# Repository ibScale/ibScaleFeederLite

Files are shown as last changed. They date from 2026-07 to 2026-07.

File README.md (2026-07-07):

# ibScaleFeederLite

`ibScaleFeederLite` is an updated version of the [Opulo LumenPNP Rev 12 Feeder](https://github.com/opulo-inc/feeder) motherboard with several enhancements.

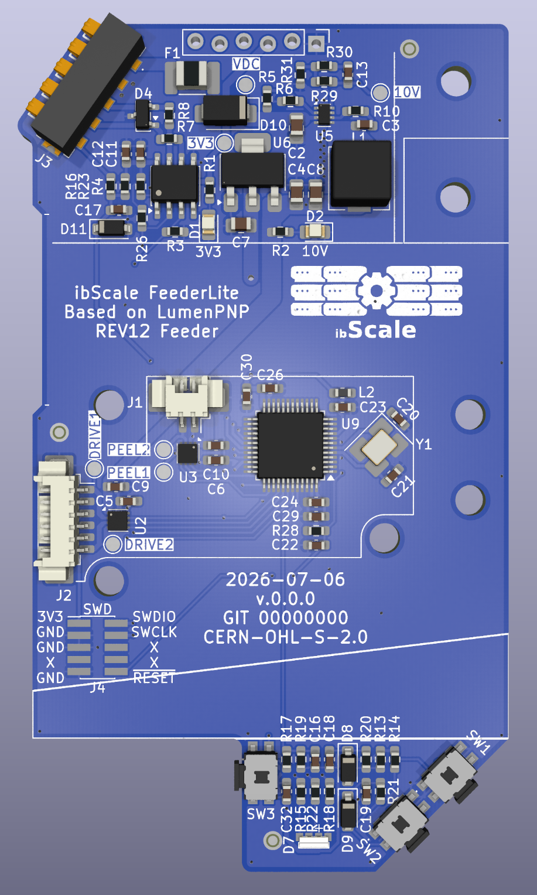
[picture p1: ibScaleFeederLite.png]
ibScaleFeederLite


## What's different from the Rev 12 motherboard

### PCB Stackup
The PCB is a 4-layer stackup with 7628 prepreg. The cost difference is negligible compared to the original 2-layer stackup. This allows for a cleaner layout with improved routing and component placement. The bottom layer of the PCB is kept as a ground layer only with no traces. Since this layer of the PCB is exposed it is very likely to get knicked, scratched, or otherwise damaged by the environment. This prevents any minor damage from affecting the operation of the feeder.

### DC/DC buck converter
The original OnSemi MC34063AD design used a 100µF input and 470µF output electrolytic capacitors. These capacitors are relatively expensive and difficult to source in low-profile heights suitable for the 8mm feeders. The large 100uF input capacitance would also cause arcing during insertion from the inrush current while charging. In addition to this, if the LumenPNP had 50 feeders plugged in the excessive bus capacitance would cause power sag (brown out) or potentially even trip the over-current protection. If the over-current protection does trip then the LumenPNP will boot loop as the 24V DC supply resets.

A Texas Instruments TPS563300 with MLCC capacitors has replaced the original design. The input capacitance has been reduced to 10uF to help prevent arcing during insertion. The reduced capacitance also helps mitigate the excessive bus capacitance start-up issue. A 0.75A PPTC fuse (F1) and diode (D1) have also been added to provide over-current and reverse-current protection.

### RS-485 transceiver
The AD/Maxim MAX3078E transceiver is the single most expensive component on the Opulo Rev12 feeder. Since the LumenPNP only operates at 57600bps there is no need to have an expensive part. The new TI THVD1400D transceiver is about 1/10th the cost and more then adequate for this application.

### Status LED
The RGB status LED has been changed to a Lite-On LTST-S33FBEGW-5A. This LED has a translucent diffuser and is designed for low current applications. It is available from a variety of suppliers and is an overall better quality indicator.

### Buttons
The original buttons were probably one of the biggest pain points on the original Rev12 design. These have been upgraded to Diptronics PTCF-V-T/R with J-hook stems. These switches are larger and available from a variety of suppliers. This along with improved debounce circuitry provide a better user experience.

### SWD connector
The original placement of the SWD connector made it difficult to use commonly available POGO pin clips like the Adafruit 5434. The connector was rotated and moved to the edge of the PCB to make using POGO pin clips easier.

## Hardware overview

| Function | Part |
|---|---|
| MCU | STM32F031C6T6 (Arm Cortex-M0, 48 MHz, 32 KB flash) |
| Motor drivers (Drive / Peel) | 2x TI DRV8837 |
| RS-485 transceiver | TI THVD1400D |
| Buck regulator | TI TPS563300 |
| Status LED | Lite-On LTST-S33FBEGW-5A |
| UP/DOWN/BOOT switches | Diptronics PTCF-V-T/R |

## Repository structure

```
ibScaleFeederLite/
├── ibScaleFeederLite.kicad_pro   KiCad project file
├── ibScaleFeederLite.kicad_pcb   PCB layout
├── ibScaleFeederLite.kicad_sch   Schematic
├── library/                      Project-specific symbols, footprints, and 3D models
└── references/                   Component datasheets
```

## Opening the project

Requires [KiCad](https://www.kicad.org/) 10 or newer. Open `ibScaleFeederLite.kicad_pro` to get started.

All custom symbols, footprints, and 3D models used by the project are included in `library/` and referenced via the project-local `sym-lib-table` and `fp-lib-table`, so no additional library setup is required.

## Bill of materials

Every component includes the manufacturer's name and part number, along with DigiKey, Mouser, and LCSC part numbers. To export a BOM, use KiCad's schematic editor: **Tools → Generate Bill of Materials**.

## License

Released under the [CERN Open Hardware Licence Version 2 - Strongly Reciprocal (CERN-OHL-S-2.0)](LICENSE.txt), consistent with the licensing of the original Opulo LumenPNP hardware it is derived from.

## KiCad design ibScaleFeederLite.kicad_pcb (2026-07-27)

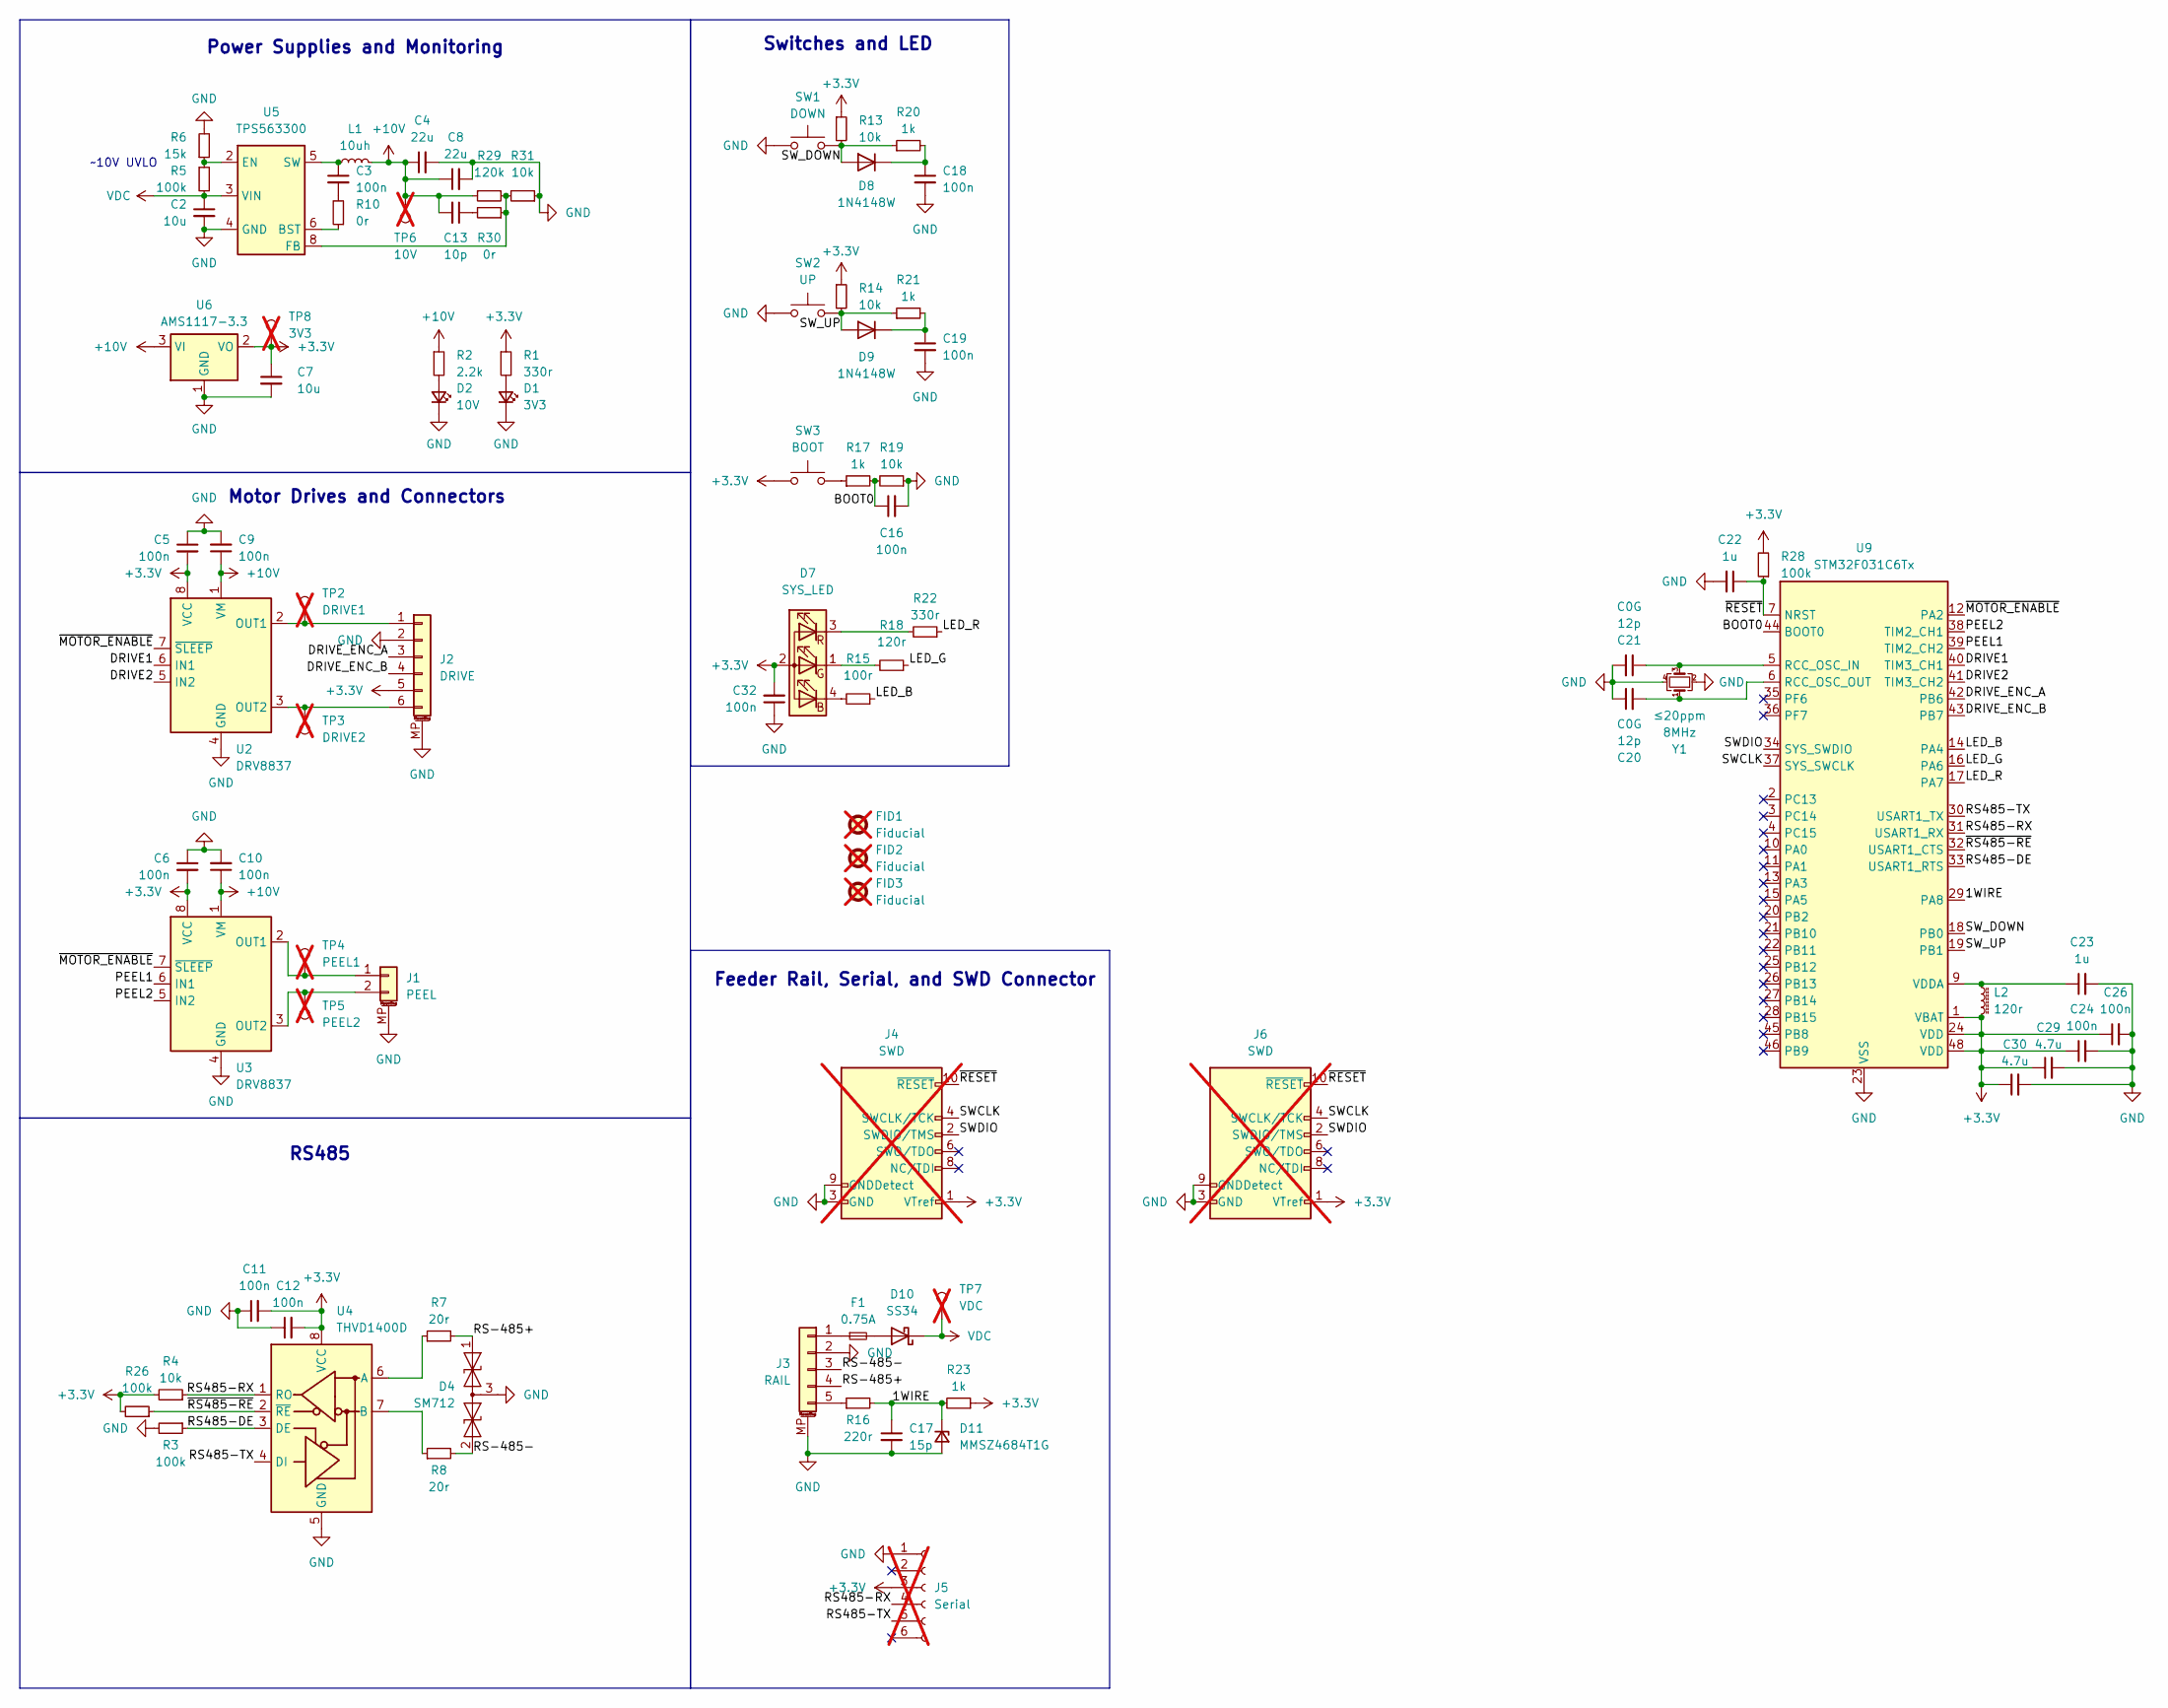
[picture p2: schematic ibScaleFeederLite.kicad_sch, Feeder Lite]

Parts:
C2: 10u; C_0805_2012Metric_Pad1.18x1.45mm_HandSolder; Tolerance X5R; Rating 50V; Manufacturer_Part GRM21BR61H106KE43L; Mouser 81-GRM21BR61H106KE3L
C3: 100n; C_0603_1608Metric_Pad1.08x0.95mm_HandSolder; Tolerance X5R; Rating 50V; Manufacturer_Part CC0603KRX7R9BB104; Mouser 603-CC603KRX7R9BB104
C4, C8: 22u; C_0805_2012Metric_Pad1.18x1.45mm_HandSolder; Tolerance X5R; Rating 25V; Manufacturer_Part CL21A226MAQNNNE; Mouser 187-CL21A226MAQNNNE
C5, C6, C9, C10, C11, C12, C24, C26: 100n; C_0603_1608Metric_Pad1.08x0.95mm_HandSolder; Manufacturer_Part CC0603KRX7R9BB104; LCSC C14663
C7: 10u; C_0805_2012Metric_Pad1.18x1.45mm_HandSolder; Manufacturer_Part GRM21BR61H106KE43L; LCSC C440198
C13: 10p; C_0603_1608Metric_Pad1.08x0.95mm_HandSolder; Tolerance CG0; Rating 25V; Manufacturer_Part CL10C100JB8NNNC; Mouser 187-CL10C100JB8NNNC
C16, C18, C19, C32: 100n; C_0603_1608Metric_Pad1.08x0.95mm_HandSolder; Manufacturer_Part CC0603KRX7R9BB104; DigiKey 311-1344-1-ND
C17: 15p; C_0603_1608Metric_Pad1.08x0.95mm_HandSolder; Manufacturer_Part CL10C150JB8NNNC; Mouser 187-CL10C150JB8NNNC
C20, C21: 12p; C_0603_1608Metric_Pad1.08x0.95mm_HandSolder; Rating C0G; Tolerance 1%; Manufacturer_Part CL10C120JB8NNNC; LCSC C38523
C22, C23: 1u; C_0603_1608Metric_Pad1.08x0.95mm_HandSolder; Manufacturer_Part CL10A105KB8NNNC; LCSC C15849
C29, C30: 4.7u; C_0603_1608Metric_Pad1.08x0.95mm_HandSolder; Manufacturer_Part CL10A475KO8NNNC; LCSC C19666
D1: 3V3; LED_0805_2012Metric_Pad1.15x1.40mm_HandSolder; Rating If=20ma, Vf=2.2v; Tolerance green; Manufacturer_Part LG R971-KN-1-0-20-R18; LCSC C2297
D2: 10V; LED_0805_2012Metric_Pad1.15x1.40mm_HandSolder; Rating If=20ma, Vf=2.2v; Tolerance green; Manufacturer_Part LG R971-KN-1-0-20-R18; LCSC C2297
D4: SM712; SOT-23; Manufacturer_Part SM712-02HTG; Mouser 576-SM712-02HTG
D7: SYS_LED; LED-SMD_4P-L3.0-W1.0-SIDE_LTST-S33FBEGW-5A; Manufacturer_Part LTST-S33FBEGW-5A; Mouser 859-LTST-S33FBEGW-5A
D8, D9: 1N4148W; D_SOD-123; Manufacturer_Part 1N4148WGW; LCSC C81598
D10: SS34; D_SMA; Manufacturer_Part SS34ALH; Mouser 821-SS34ALH
D11: MMSZ4684T1G; D_SOD-123; Manufacturer_Part MMSZ4684T1G; Mouser 863-MMSZ4684T1G
F1: 0.75A; Fuse_1812_4532Metric_Pad1.30x3.40mm_HandSolder; Manufacturer_Part PTS181233V075; Mouser 504-PTS181233V075
FID1, FID2, FID3: Fiducial; Fiducial_1mm_Mask2mm; not fitted
J1: PEEL; Molex_PicoBlade_53261-0271_1x02-1MP_P1.25mm_Horizontal; Manufacturer_Part 53261-0271; Mouser 538-53261-0271
J2: DRIVE; Molex_PicoBlade_53261-0671_1x06-1MP_P1.25mm_Horizontal; Manufacturer_Part 53048-0610; Mouser 538-53048-0610
J3: RAIL; 009155005541006; Manufacturer_Part 009155005541006; Mouser 581-009155005541006
J4, J6: SWD; PinHeader_2x05_P1.27mm_Vertical_SMD; not fitted
J5: Serial; PinHeader_1.27mm_1x06_FrictionFit; not fitted
L1: 10uh; L_TDK_VLS6045EX_VLS6045AF; Manufacturer_Part VLS6045EX-100M; Mouser 810-VLS6045EX-100M
L2: 120r; L_0603_1608Metric_Pad1.05x0.95mm_HandSolder; Manufacturer_Part MFBM1V1608-121-R; LCSC C14709
R1: 330r; R_0603_1608Metric_Pad0.98x0.95mm_HandSolder; Manufacturer_Part RC0603FR-13330RL; Mouser 603-RC0603FR-13330RL
R2: 2.2k; R_0603_1608Metric_Pad0.98x0.95mm_HandSolder; Manufacturer_Part RT0603FRE132K2L; LCSC C4190
R3, R26: 100k; R_0603_1608Metric_Pad0.98x0.95mm_HandSolder; Manufacturer_Part RC0603JR-13100KL; LCSC C25803
R4, R13, R14, R19: 10k; R_0603_1608Metric_Pad0.98x0.95mm_HandSolder; Manufacturer_Part RC0603FR-0710KP; LCSC C25804
R5, R28: 100k; R_0603_1608Metric_Pad0.98x0.95mm_HandSolder; Manufacturer_Part RC0603JR-13100KL; Mouser 603-RC0603JR-13100KL
R6: 15k; R_0603_1608Metric_Pad0.98x0.95mm_HandSolder; Manufacturer_Part WR06X153 JTL; Mouser 791-WR06X153JTL
R7, R8: 20r; R_0603_1608Metric_Pad0.98x0.95mm_HandSolder; Manufacturer_Part AC0603JR-0720RL; Mouser 603-AC0603JR-0720RL
R10, R30: 0r; R_0603_1608Metric_Pad0.98x0.95mm_HandSolder; Tolerance 1%; Manufacturer_Part RC0603FR-100RL; Mouser 603-RC0603FR-100RL
R15: 100r; R_0603_1608Metric_Pad0.98x0.95mm_HandSolder; Manufacturer_Part RK73H1JTTD1000F; LCSC C22775
R16: 220r; R_0603_1608Metric_Pad0.98x0.95mm_HandSolder; Manufacturer_Part RMCF0603JT220R; Mouser 708-RMCF0603JT220R
R17, R20, R21, R23: 1k; R_0603_1608Metric_Pad0.98x0.95mm_HandSolder; Manufacturer_Part RC0603FR-131KL; LCSC C21190
R18: 120r; R_0603_1608Metric_Pad0.98x0.95mm_HandSolder; Manufacturer_Part RMCF0603FT120R; LCSC C22787
R22: 330r; R_0603_1608Metric_Pad0.98x0.95mm_HandSolder; Manufacturer_Part RC0603FR-13330RL; LCSC C23138
R29: 120k; R_0603_1608Metric_Pad0.98x0.95mm_HandSolder; Tolerance 1%; Manufacturer_Part RC0603JR-07120KL; Mouser 603-RC0603JR-07120KL
R31: 10k; R_0603_1608Metric_Pad0.98x0.95mm_HandSolder; Tolerance 1%; Manufacturer_Part RC0603FR-0710KP; Mouser 603-RC0603FR-0710KP
SW1: DOWN; PTCFVTR; Manufacturer_Part PTCF-V-T/R; Mouser 113-PTCF-V-T/R
SW2: UP; PTCFVTR; Manufacturer_Part PTCF-V-T/R; Mouser 113-PTCF-V-T/R
SW3: BOOT; PTCFVTR; Manufacturer_Part PTCF-V-T/R; Mouser 113-PTCF-V-T/R
TP2: DRIVE1; TestPoint_Pad_D1.5mm; not fitted
TP3: DRIVE2; TestPoint_Pad_D1.5mm; not fitted
TP4: PEEL1; TestPoint_Pad_D1.5mm; not fitted
TP5: PEEL2; TestPoint_Pad_D1.5mm; not fitted
TP6: 10V; TestPoint_Pad_D1.5mm; not fitted
TP7: VDC; TestPoint_Pad_D1.5mm; not fitted
TP8: 3V3; TestPoint_Pad_D1.5mm; not fitted
U2, U3: DRV8837; WSON-8-1EP_2x2mm_P0.5mm_EP0.9x1.6mm_ThermalVias; Manufacturer_Part DRV8837DSGR; Mouser 595-DRV8837DSGR
U4: THVD1400D; SOIC-8_3.9x4.9mm_P1.27mm; Manufacturer_Part THVD1400DR; Mouser 595-THVD1400DR
U5: TPS563300; SOT-583-8; Manufacturer_Part TPS563300DRLR; Mouser 595-TPS563300DRLR
U6: AMS1117-3.3; SOT-223-3_TabPin2; Manufacturer_Part LM1117MPX-3.3/NOPB; Mouser 926-LM1117MPX3.3NOPB
U9: STM32F031C6Tx; LQFP-48_7x7mm_P0.5mm; Manufacturer_Part STM32F031C6T6TR; Mouser 511-STM32F031C6T6TR
Y1: 8MHz; Crystal_SMD_3225-4Pin_3.2x2.5mm_HandSoldering; Tolerance ≤20ppm; Manufacturer_Part ECS-80-8-33-JGN-TR3; LCSC C648984

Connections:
+3.3V: C5.2, C6.2, C7.1, C11.2, C12.2, C24.1, C26.1, C29.1, C30.1, C32.2, D7.2 (A), J2.5, J4.1 (VTref), J5.3, J6.1 (VTref), L2.2, R1.1, R4.2, R13.1, R14.1, R23.1, R26.2, R28.2, SW3.1, TP8.1 (1_1), U2.8 (VCC), U3.8 (VCC), U4.8 (VCC), U6.2 (VO), U9.1 (VBAT), U9.24 (VDD), U9.48 (VDD)
+10V: C4.1, C8.1, C9.1, C10.1, C13.2, L1.2, R2.1, R29.1, TP6.1 (1_1), U2.1 (VM), U3.1 (VM), U6.3 (VI)
/1WIRE: C17.1, D11.1 (K), R16.2, R23.2, U9.29 (PA8)
/BOOT0: C16.1, R17.2, R19.2, U9.44 (BOOT0)
/DRIVE1: U2.6 (IN1), U9.40 (TIM3_CH1)
/DRIVE2: U2.5 (IN2), U9.41 (TIM3_CH2)
/DRIVE_ENC_A: J2.3, U9.42 (PB6)
/DRIVE_ENC_B: J2.4, U9.43 (PB7)
/LED_B: R15.1, U9.14 (PA4)
/LED_G: R18.1, U9.16 (PA6)
/LED_R: R22.1, U9.17 (PA7)
/PEEL1: U3.6 (IN1), U9.39 (TIM2_CH2)
/PEEL2: U3.5 (IN2), U9.38 (TIM2_CH1)
/RS485-DE: R3.1, U4.3 (DE), U9.33 (USART1_RTS)
/RS485-RX: J5.4, R4.1, U4.1 (RO), U9.31 (USART1_RX)
/RS485-TX: J5.5, U4.4 (DI), U9.30 (USART1_TX)
/RS-485+: D4.1 (A1), J3.4, R7.2
/RS-485-: D4.2 (A2), J3.3, R8.2
/SWCLK: J4.4 (SWCLK/TCK), J6.4 (SWCLK/TCK), U9.37 (SYS_SWCLK)
/SWDIO: J4.2 (SWDIO/TMS), J6.2 (SWDIO/TMS), U9.34 (SYS_SWDIO)
/SW_DOWN: D8.2 (A), R13.2, R20.1, SW1.2, U9.18 (PB0)
/SW_UP: D9.2 (A), R14.2, R21.1, SW2.2, U9.19 (PB1)
/~MOTOR_ENABLE: U2.7 (~SLEEP), U3.7 (~SLEEP), U9.12 (PA2)
/~RESET: C22.1, J4.10 (~RESET), J6.10 (~RESET), R28.1, U9.7 (NRST)
/~RS485-RE: R26.1, U4.2 (~RE), U9.32 (USART1_CTS)
GND: C2.2, C4.2, C5.1, C6.1, C7.2, C8.2, C9.2, C10.2, C11.1, C12.1, C16.2, C17.2, C18.2, C19.2, C20.1, C21.2, C22.2, C23.2, C24.2, C26.2, C29.2, C30.2, C32.1, D1.1 (K), D2.1 (K), D4.3 (common), D11.2 (A), J1.MP (MountPin), J2.2, J2.MP (MountPin), J3.2, J3.MP (MountPin), J4.3 (GND), J4.5 (GND), J4.9 (GNDDetect), J5.1, J6.3 (GND), J6.5 (GND), J6.9 (GNDDetect), R3.2, R6.2, R19.1, R31.1, SW1.1, SW2.1, U2.4 (GND), U2.9 (GND), U3.4 (GND), U3.9 (GND), U4.5 (GND), U5.4 (GND), U6.1 (GND), U9.8 (VSSA), U9.23 (VSS), U9.47 (VSS), Y1.2, Y1.4
unnamed: C3.2, R10.2
unnamed: C13.1, R30.2
unnamed: D1.2 (A), R1.2
unnamed: D2.2 (A), R2.2
unnamed: D7.4 (BK), R15.2
unnamed: D7.1 (GK), R18.2
unnamed: D7.3 (RK), R22.2
unnamed: C18.1, D8.1 (K), R20.2
unnamed: C19.1, D9.1 (K), R21.2
unnamed: D10.2 (A), F1.2
unnamed: J1.1, TP4.1 (1_1), U3.2 (OUT1)
unnamed: J1.2, TP5.1 (1_1), U3.3 (OUT2)
unnamed: J2.1, TP2.1 (1_1), U2.2 (OUT1)
unnamed: J2.6, TP3.1 (1_1), U2.3 (OUT2)
unnamed: F1.1, J3.1
unnamed: J3.5, R16.1
unnamed: R17.1, SW3.2
unnamed: R7.1, U4.6 (A)
unnamed: R8.1, U4.7 (B)
unnamed: R10.1, U5.6 (BST)
unnamed: R5.1, R6.1, U5.2 (EN)
unnamed: R29.2, R30.1, R31.2, U5.8 (FB)
unnamed: C3.1, L1.1, U5.5 (SW)
unnamed: C21.1, U9.5 (RCC_OSC_IN), Y1.3
unnamed: C20.2, U9.6 (RCC_OSC_OUT), Y1.1
unnamed: C23.1, L2.1, U9.9 (VDDA)
VDC: C2.1, D10.1 (K), R5.2, TP7.1 (1_1), U5.3 (VIN)

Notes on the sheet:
~10V UVLO
RS485
Power Supplies and Monitoring
Feeder Rail, Serial, and SWD Connector
Motor Drives and Connectors
Switches and LED

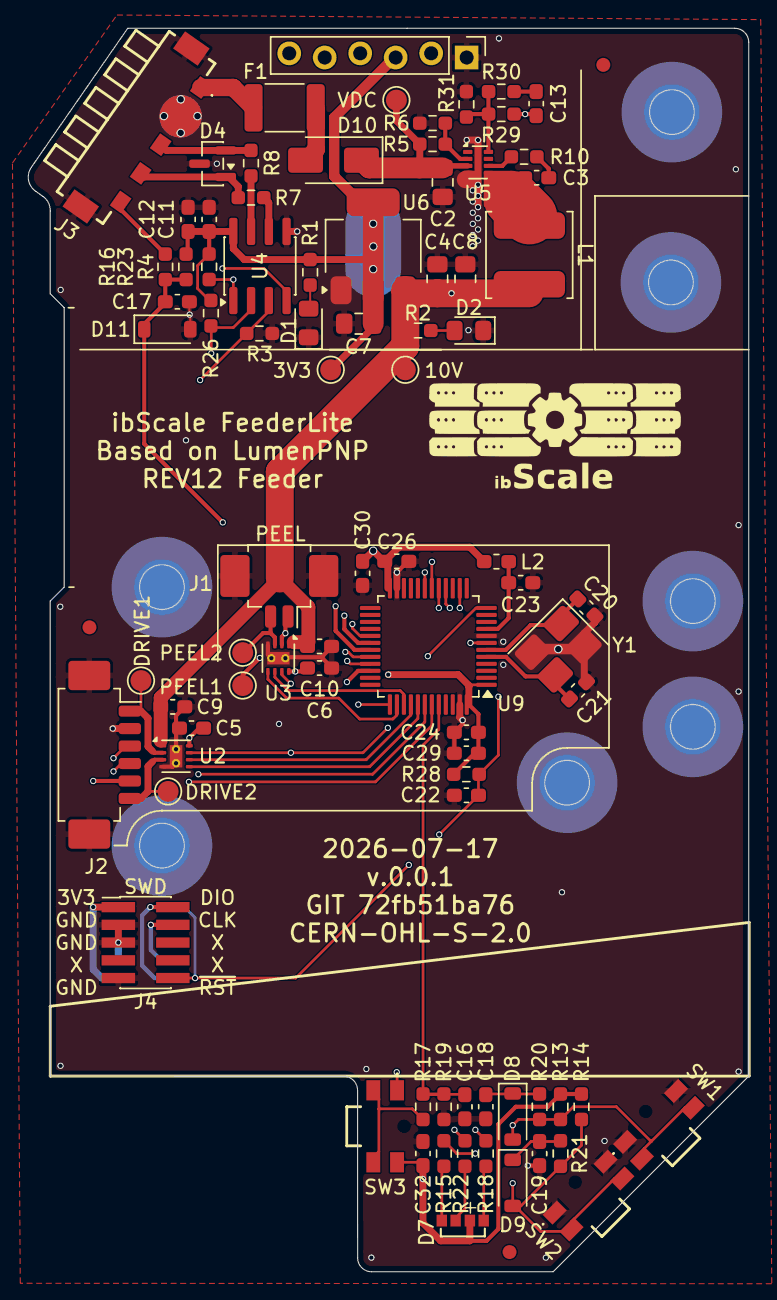
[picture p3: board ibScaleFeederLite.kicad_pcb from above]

Board: 4 copper layers, 51.6 x 89.0 mm, 87 parts (1 on the bottom side), 53 nets.

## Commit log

2026-07-07 Initial commit: ibScaleFeederLite KiCad project
    [ibScaleFeederLite.kicad_pcb, ibScaleFeederLite.kicad_sch]
2026-07-07 Add labeling to SWD connector
    [ibScaleFeederLite.kicad_pcb]
2026-07-07 Have the LDO use solid fille for heat dissipation
    [ibScaleFeederLite.kicad_pcb]
2026-07-07 Add SWD header to back of board for in-place debug of a running feeder.
    [ibScaleFeederLite.kicad_pcb, ibScaleFeederLite.kicad_sch]
2026-07-17 V.1.0 pre-commit
    [ibScaleFeederLite.kicad_pcb, ibScaleFeederLite.kicad_sch]
2026-07-17 V1.0 ready
    [ibScaleFeederLite.kicad_pcb, ibScaleFeederLite.kicad_sch]
2026-07-17 make SWD pinout mirror on both sides
    [ibScaleFeederLite.kicad_pcb]
2026-07-17 Clean up some routing
    [ibScaleFeederLite.kicad_pcb]
2026-07-21 Change VDDA ferrite to 120-ohm for better parts availability
    [ibScaleFeederLite.kicad_pcb, ibScaleFeederLite.kicad_sch]
2026-07-27 update L1 to use correct VLX4045EX footprint instead of generic one
    [ibScaleFeederLite.kicad_pcb, ibScaleFeederLite.kicad_sch]
